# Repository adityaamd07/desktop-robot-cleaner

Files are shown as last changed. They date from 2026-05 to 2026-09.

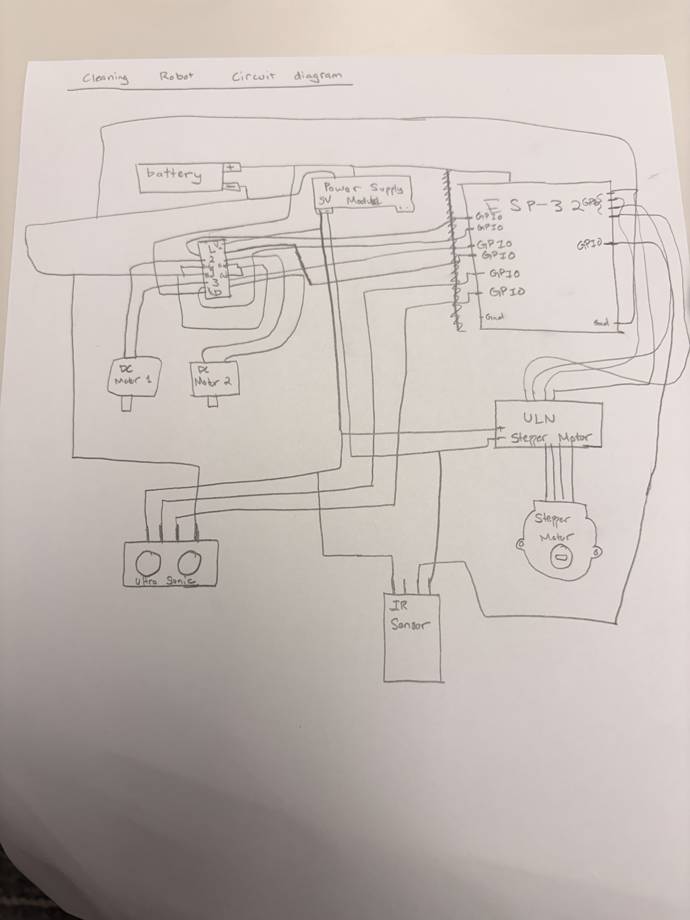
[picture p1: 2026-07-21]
docs/sketches/cleaning_robot_wiring_diagram_v1.jpeg

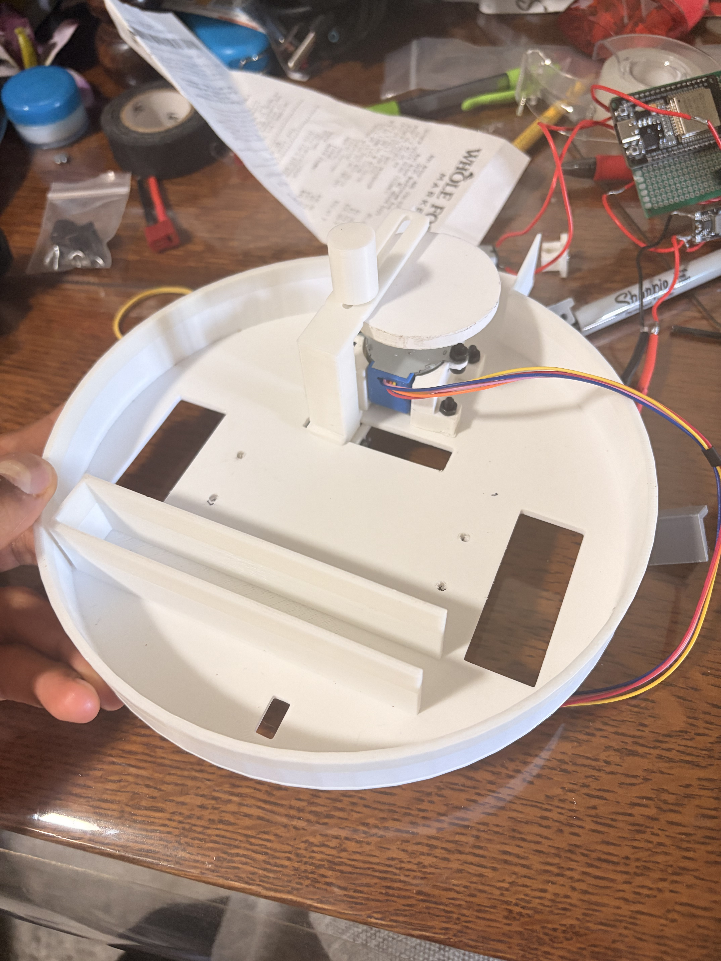
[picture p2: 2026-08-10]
docs/media/top_view_chassis_w_mechanism.jpeg

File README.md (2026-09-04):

# desktop-robot-cleaner
The goal of this project is for myself, a rising sophomore mechanical engineering student, to create a desktop cleaning with autonomous capabilities. The individual goals and markers of this project have changed quite a bit since its inception in May, but I have learned quite a bit by doing this and it has been a lot of fun!

**Project Status:** In progress

## Project accomplishments, current happenings, and future goals 
Since the project's start I have done the following: 
- Designed and fabricated a 7" circular chassis, ensuring that the chassis is able to fit tight space constraints between all components
- Designed a Scotch Yoke mechanism to move a cleaning pad back and forth, effectively sweeping areas. 
- Selected the proper materials, including chassis make, sensors, motors, and main chip driving performance
- Breadboard tested and permanently soldered components, utilizing IC sockets, screw terminals, and multmeter testing to ensure connectivity. 
- Designed a C++ firmware architecture using PlatformIO to have manual drive and sweeping capabilities

I am currently doing the following: 
- Attempting to synthesize C++ firmware, physical mechanisms, and electrical components together in one working system 
  by using the ESP32's bluetooth capabilities to handle manual driving and sweeping

Future Goals/Ideas: 
- Redesign chassis to be a 7"x 7" square, which will result in better use of space as many components are rectangular in nature
- Add autonomous capabilities
    - IMU + Encoders? 
    - Something else??
- Introduce a spray mechanism so the robot can sanitize a surface and sweep it in one pass. 

## Repo Structure: 
- docs
    - media: For all photos and vidoes I take during the project
    - sketches: a folder of all planning sketches I do for this project. To me, a planning sketch is one that I do simply to view an overall layout. Crucially, it does NOT have any dimensions. 
    - design_decisions: A log of decisions made throughout this project, including the rationale behind these decisions
    - materials purchased: a bill of all things bought for this project in order to keep tally of budget
    - components_list: a list of all components necessary for this project, both purchased and not yet acquired.
    - current: a planning document to organize tasks I need to accomplish in a given day, and the following days and week
- hardware: 
    - Chassis: all CAD models or engineering drawings including the full robot chassis
    - cleaning mechanism: all CAD models or engineering drawings/reasonings relating to the cleaning mechanism
- firmware: Used platformio in VSCODE
    - include: contains headerfiles
    - lib: any imported libraries
    - src: all source code
    - test: any test code
    - pio/build: ESP32 files preloaded by platformio
    - vscode: json files preloaded by vscode

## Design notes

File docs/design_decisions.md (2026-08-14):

# Design Decision Log

## Robot Chassis Shape -- 5/4/26
To begin this project, I considered two main shapes for the robot chassis: 

- Rectangular
- Circular 

I initially considered the rectangular shape because, to me, it simply made the most sense. 
Most of the electronic components are rectangular in shape, and it would be the most space 
efficient to have the robot be a rectangle, as then each component could slot in nicely. 
This has problems though: a rectangle is not as easy to maneuver as a circle, and for this robot to be autonomous,
it would have to be able to make fine tune adjustments in its position, which is much more difficult for a box to manage. 
Additionally, a rectangular shape would also likely require four wheels, would significantly increase the cost of the project, 
which is something I would like to avoid. The circular shape is less space efficient, 
but it is much superior in its maneuverability, which will make my life a lot easier when it comes to making this thing 
autonomous. According to my initial block sketches, the circle should contain enough space to properly manage components, 
and I can definitely find ways to make use of the shape to my advantage. 

**Decision:** Circular Chassis

## Chassis Diameter - 5/5/26
I considered a 6 in, 7 in, and 8 in diameter for the robot size. To determine the size that felt right for my desk, I drew a circle of 6, 7, and 8 in diameter on a sheet of paper and look at their relative size compared to my desk. I decided that 7 in would leave enough room for electrical components, while simultaneously allowing for enough manuverability for a desk my size. 
**Decision:** 7 inch diameter for chassis

## Robot Scrubbing Mechanism -- 5/5/26
I explored two options today of how to scrub the surface of its materials. The first option I considered is a rotating shaft that is in contact with the surface at all times. This design idea presented problems, however. Firstly, this rotating shaft would likely have to be a brush, not a dusting pad. A rotating dusting pad, to me, is not an effective way to clean, as the dirt is more likely to simply be spread out more rather than actually be collected. This, however, presented its own challenges. Even if I decided to do a brush, I would still likely need a dust  collection system so that the dirt is removed from the surface. This is much more mechanically complex, but also this is not very feasible to combine into a the second stage: santizing. How could I possible turn this dust collection system into a sanitizer? Suddennly, this begins to sound like two different machines.

The second option I considered is a oscillating dusting pad that is in constant contact with the surface. This option to me seems the better option. A scrubber that moves back and forth is much more intuitive, as that is how a normal person would dust a surface: scrubbing a swiffer back and forth. And, by using a swiffer pad specifically designed to collect dirt, I would rid the need of a dust collection system. This ties perfectly into the sanitizing stage: people sanitize surfaces by moving a clorax wipe or an equivalent back and forth, so it makes sense for a robot to do that as well. So, after dusting and removing larger debris, I can simply replace the dusting pad with a small mop pad, and my robot will instead turn into a sanitizer. 

**Decision:** An oscillating dusting that scrubs that surface back and forth

Further Questions for next steps: 
- How will I make the pad oscillate back and forth? The only way I know of to make things move in a robot is a motor. Is there any other way? Otherwise, how do I turn rotational motion into linear?
- How will I attach these pads to the robot?
- How will I change out these pads?

## Overall Drive train decision -- 5/11/26
I considered a few  options for my vehicle drivetrain, or how to actually get my robot moving. The first idea was to model my robot after a car: four wheels, two in the front and two in the back, each connected with a rotating shaft. I had considered using one motor to drive one of the wheel-shaft combo, but then quickly realized that I would have no way to turn the car. I then researched how a modern car handles steering: a rack and pinion setup connected to a steering wheel that would angle the wheels 

This was definitely interesting, but I deemed it far too mechanically complex for what I am trying to accomplish. Besides, this idea would require buying four wheels, which would increase cost. I then considered both a two and three wheel design. The two wheel design would be realtively simple: two wheels, one on each side of the chassis, each connected to a DC motor. These wheels would not be connected to a central shaft, but would fall in line along the diameter of the robot. This would allow for easy manuervering, as turning the robot would be as easy as turning one of the motors on and the other off. 

I also briefly considered a 3 wheel design. This would keep the two wheel system, but add a third castor wheel towards the front of the robot in order to achieve greater stability. For this design, I could either keep the two wheels at the diameter, or shift it further back, along a chord of the circle. For now, I will pocket this design. I plan to have the scrubbing mechanism in constant contact with the surface, so that _should_ provide enough stability for the robot to tip over. I will move forward with planning and building an initial prototype, and then after some testing, I will decide whether a castor wheel is necessary. 

**Decision:** two wheel drivetrain with each wheel connected to its own motor

**Further Questions:**
 - Given that I know what my wheels system looks like, can I begin writing code for driving the robot, assuming manual inputs?
 - I previously decided on an oscillating system to scrub. Where should I place this system? The front? The back?
 - Should I have two levels in my robot, or is one enough for the components I need?

## Chassis Layout Planning -- 5/14/26
I worked in MS Paint today to plan out my chassis, working through placing different components in my circular frame. I have arranged a preliminary layout, which can be found docs/sketches. The main thing I wanted to figure out was how to fit in the scrubbing mechanism, and the answer is that I have no answer. I need to decide on a scrubbing mechanism, and come up with sketches before I can go any further. I have some ideas on a way to lower the srubbing mechanism further down below the chassis floor, thus making leaving much more space on the chassis itself for other components. 

No decision made today. Any Further Question mainly revolves around how I am going to design this scrubbing mechanism. 

## Scrubbing Mechanism Sketching --5/21/26
I used a penci, a piece of paper, and a ruler to sketch out and define my mechanism. These sketches are visible in the hardware folder. I worked through many things. Firstly, I decided to use velcro command strips in order to attach the cleaning pads (duster or mop pad) to the mount. This allows for the simplest method of attaching and removing pads. An additional option I considered was using metal strips and magnets, but I was unsure whether the magnetic force would survive the scrubbing mechanism, and decided to go for velcro as the simpler option. I then, using the 7 inch diameter of my robot and the average length of a commmand strip as constraints, drew out my scrubbing mechanism. I decided on a 2.5 inch diameter wheel spinning, as this would allow for 5 inches of linear coverage, according to l = 2r, a governing equation for crank and slider mechanisms. 

Finally, I have decided to use a stepper motor to run the scrubbing mechanism. I initially considered a servo motor, but quickly realized that, for Phase 2 of this project, I will need to precisely move the cleaning pad mount to a certain spot to allow for consistent changing of pads. Thus, I decided to use a stepper motor as that will provide me greater precision that a servo. 

**Decisions**: Velcro linkages between pads and mount, 2.5 inch diameter wheel for crank and slider mechanism, and swapping servo motor with stepper motor

Further Questions:
- how will I link the pieces in my project together? screws? custom 3d printed joinings? 
- In my initial sketches, I assumed one velcro piece would be enough. Will this hold to be true? 

## Components Update -- 5/29/26
This is multiple design decisions rolled into one, so I will try an dedicate a few paragraphs, one for each decisions. First,  I decided on the G12 N20 DC motors to drive my robot. Upon research, I discovered that N20 motors are a classic choice for robots, so I decided to use them as a useful starting point for this project. I decided on the G12 N20 motors because this was the type that I found the most documentation for, which is useful when deciding power current requirements. 

I also decided to use the L293D motor driver and the ULN2003 Stepper Motor Driver for my DC and stepper motors respectively. The primary rationale for this decision is that they came with the ELEGOO kit that I ordered and are useful for prototyping. If needed, I will order a different motor driver. It is worth mentioning that, according to my calculations, the L293D driver does not provide enough current for my motors IF both of them stall. Ideally, I would design my system to avoid my motors stalling, but I will note this here and will likely replace the L293D as I move out of prototyping. Additionally, I have decided to use the power supply module given with the ELEGOO kit to regulate power for now. 

Finally, the battery. I first researched and noted the documented voltage and max current values for components that would need to connect to the battery. These values can be found in docs/commponents. By summing the max current values for the stepper motor, both DC motors, and the ESP 32 board, I arrive at 2080 mAh. Because I would like the robot to run for 30 minutes on one charge, I decided on a 1040 mA minimum current requirement. I then applied a 20% buffer (1040/0.8) to bring that number up to 1300 mAh. To be safe, I decided that 1500 mAh should be good for the battery. The DC motors require the largest voltage at 6V, and the VIN pin on the ESP32 is only able to handle up to 12V. To be safe, I decided to go for between the 5-8V range, which should be more than safe for the ESP32. Therefore, I decided to use a 7.4V Lipo Battery. This was one of the cheaper batteries I saw, yet simultaneouly met all of my requirements. 

These decisions ultimately provide a natural power architecture. The battery will connect to three components: The ESP32 VIN, which handles up to 12V, the L293D motor driver, and the power supply module. The power supply module will then power the stepper motor and its driver, both of which require 5V. 

**Decisions:** G12 N20 Motors for driving robot motion, L293D motor driver and the ULN2003 Stepper Motor Driver for DC and stepper motors respectively, power supply module from kit for voltage regulation. 7.4V Lipo Battery with 1500 mAh. Power Architecture has been decided. 

Further Questions:
 - What size wheels will I need for robot.
 - How many IR sensors do I truly need?
 - what is the true ESP32 current draw? My current number is a rough estimate. 

## IR Line Sensors Quantity and Placement + Robot Driving Pattern -- 5/29/26
In order to decide how many IR sensors I needed I first need to decide how my robot is going to move. I quickly decided on a lawnmower style pattern, with only forward motion and pivoting. This is the simplest way I could think of to code the robots motion, and will make planning this project much easier. Therefore, I have decided on 2 IR sensors, one in the very front and one in the very back. When the Robot is moving forward, we will obviously need a sensor in the front to detect when the robot is off the edge. When pivoting, however, the front and back of the robot will travel in a arc around the wheel that has been designated the pivot. Obviously, whatever wheel is pivot will depend on the direction turning, but this means that the front or back will likely move off the desk if close to the edge of the desk. Having these two sensors here will prevent that from happening. 

**Decision:** Lawn Mower Traversal pattern and 2 IR sensors in the front and back for edge detection. 

## Wheel Diameter size  -- 5/31
After sketching a quick dimensioned paper sketch (visible in docs/sketches folder), I have decided on 3 inch wheels for the drive train of this robot. This decision was made primarly due to an estimated thickness of a swiffer dusting pad. Unfortunately, I do not have access to the actual swiffer pads for the moment, but online estimates ranged from 1.5-2" when fully fluffed. To get the effectiveness of the pad, it will need to be compressed. Thus, I decided to allocate roughly 1" of space below the robot for the pad itself, with 0.5" for the mount to hold the pad.

With 1.5" of space below the robot, I naturally concluded that I needed 3" diameter wheels. I had already planned on keeping the motor housing for the wheels inside the chassis, which would mean that the middle of the wheel would have to be in the chassis, in line with the motor axle. This mean I would need a 1.5" radius wheel to keep the robot 1.5" off the robot. Additionally, I have only ordered 2 wheels for now. I will test using the scrubbing mechanism itself as a third point of support: if this is too unrealiable, I will research and decide to implement a caster wheel.

**Decision:** 3" wheels will be used in drive train system. Will consider caster wheel after first prototype. 

Further Questions: N/A

## Wheel Diameter resize + Dust Pad change  -- 6/23
I've been on vacation for a while, so work on this project has slowed, and I have gotten lax at updating this repo. I've been working on the robot chassis design in my free time, and have since recognized that I simply cannot fit everything in as it stands with 3 inch wheels. With the battery I have chosen and the restraint of a 7 inch diameter, there simply isn't enough space to fit everything in as it stands. Thus, I've decided on downsizing to 2 inch wheels, which will give me roughly 1 inch of ground clearance. I feel comfortable with this due to a recent discovery I have made: swiffer dusting pads. Previously, I was working under the assumption that I would be using large, handheld fluffy dusting pads for my robot. I have since visited target and discovered that swiffer actually makes thinner, dusting pads intended to be put on a mop. With these, I can assume the pad has negligable thickness and not be concerned with fitting a thick pad under my robot. 

**Decision:** 2 inch wheels will be used in the drive train system, and I will be switching to thinner swiffer dusting pads. 

Further Questions:
 - How will I acquire these new wheels? 3D print or buy new ones?
 - How will I keep track of the distance that the robot moves? Math or a device?
 - For this robot to work, I will need both the ultrasonic sensor and the IR line tracker in the front of the robot. How will I reconcile the fact that both these devices need to take up a similar about of space?

 ## Wheel acquisition -- 6/25
 After some thinking, I have decided to buy wheels online. This is a bit unfortunate because I already bought some 3 inch wheels that are now useless, but I digress. After researching online, I have discovered that the tolerances to make these wheels fit into the the motor are very finnicy for a 3D printer, and that the DC motor I have chosen, G12-N20, already has wheels that you can buy for cheap on amazon. Thus, I am deciding to buy one of these wheels, which I will order soon. Now this does come with a drawback, which is that the only wheels that I can find are 43 mm wheels, which is roughly 1.7 inches. This is slightly smaller than the wheels that I originally wanted, the 2 inch wheels. This will leave me even less ground clearance than I originally intended. I have decided that to work with this, and attempted to make my cleaning mechanism fit in the roughly 0.85 inches of ground clearance I know have. 

 **Decision:** I will purchase my wheels for the drive train. This will shrink my ground clearance, which I have decided to work with. 

 Further Questions:
 - How should I opt to fit in my cleaning mechanism under the robot now that my space has shrunk. 
 - How will I make the cleaning pads replacable? 
 - How should I think about mounting my step motor to the chassis to drive the cleaning mechanism. 

 ## Cleaning Pad -- 7/4
 Because I have now switched to the thinner dusting pads used on maps, I now have a greater degree of flexibility in deciding the length of the cleaning pad itself. I have decided on a 4x2 inch cleaning pad dimensions, which I will note in my components list. I arrived at this number largely as a reasonable guess to what would a good length be. 8 inches of surface area to clean should certainly be a big enough number for a countertop/desk while still being small for the robot, and this will also make it (roughly) the size of my velcro strips. This makes it so that there is little overhang from my cleaning pad over my velcro strip, which I believe is preferable. This dimension is very much subject to change as I begin to run the numbers and decide if the mechanism I want to fit is possible. 

 **Decision:** Cleaning pad length will (temporarily) be 4x2 in. 
 **Next Steps:** Based on this length, redo all of the math and redesign the cleaning mechanism with the chassis and this new constraint in mind. 

 ## Cleaning Mechanism significant redesign -- 7/4
 I have had a significant realization while working on measuring out this cleaning mechanism. I kept running into the issue where I was struggling to balance the amount of space I had. with the constraint of the 6.5" chord, I simply could not figure out a way to balance the lengths. This was especially hard due to my realization that, since I am elevating the motor shaft above the floor of the chassis, the length of the slider is NOT simply 2 times the radius, but a little more than that, which would involve a lot of decently complex math to do so, as it introduces an angle of elevation since the crank arm is not perfectly inline with the slider. By using a linkeage system and having the crank and the slider side by side, I simply would have to make the slider so small that the cleaning pad would be hardly oscillating, which to me, defeats the whole purpose of having an oscillating cleaning pad in the first place. 

 This resulted in me researching other ways for me to convert rotational motion into linear motion. I have since arrived at the scotch yoke mechanism. With this mechanism, the crank arm is able to sit perpindicular to the slider, which means that I can place my stepper motor above or below the slit in the floor, where I have signficantly more space than I do right now. This will greatly simplify my design. Best of all, the mechanism uses a simple L = 2r for the slider length, and does not require the complex math that the linkeage system does. 

 **Decision:** Shift from a linkeage system to a scotch yoke system for my cleaning mechanism. 
 **Further Questions/Steps:** From here, I need to start sketch what this system will look like and dimension it on paper. From there, I can CAD the model and have it ready to be added to the main chassis assembly. 

 ## Step Motor Mount -- 7/6
 I have just finished designing my Step Motor Mount, which can be found for the time being in hardware/chassis. For the future, I might add a mounts folder in hardware due to the fact that I have design multiple mounts throughout the project. Design for this mount was pretty straight forward, although the main decision here comes at the walls of the mount. The way I have it, the walls are very thin towards side holes for the motor. I worry about structural integrity of the mount with such thin walls, but I have for the time being decided to keep this as the first version and design a different mount later. 

 **Decision:** Use current iteration with thin walls for the Step Motor Mount, and decide in the future whether the mount needs redesigning. 

 ## Cleaning Mechanism decisions -- 7/6
 Two decisions to report here after doing CAD on the new cleaning mechanism. The first is relating to the "crank arm" of the mechanism. I have decided to use a circle attached to the motor shaft for this project, because I deemed it simpler to design while getting full functionality. I worried particularly about accidentally designing an arm too small and thing that would snap, and with a circle, the chances of that happening dwindle significantly. On a practical note, using a circle made it easier to see the amount of space the mechanism would be taking place, rather than a single arm where I would have to visualize its path through one shaft rotation. Additionally, I have decided on a crank radius of 1 inch, for roughly 2 inches of travel. 

 The second relates to the crank pin. I initially considered designing and 3D printing a dowel that would fit into the circle, and thus be used to shift the cleaning pad as the wheel turned. I worry, however, that the plastic on plastic friction will degrade the dowel, and make the mechanism fail over time. I have thus decided to use a a steel rod as a dowel, that I will cut to length. Plastic on metal should result in a much smoother glide, and importantly, should not seriously degrade the plastic over time. 

 **Decisions:** 2 inch Circle with steel rod pin for the crank arm. 

 **Further Question:** What size steel rod should I use for the pin, and will choosing to do this increase my costs severely? 

## Cleaning Mechanism Decisions  -- 7/7 
Today, I have finished my second version of the cleaning mechanism, which is very exciting. One of the decisions I arrived at today was deciding the size of the steel dowel I will use. For simplicity, I will 3mm dowel, as I found multiple 3mm steel rods for relatively cheap on Amazon. 

Additionally, I must begin to consider the actual attachment of the cleaning pad. For this, I was considering designing a piece that will hold a velcro strip that the cleaning pad will attach to, and then towards the top of that piece, a place to put an adhesive magnet. The main reason I want to use magnets to attach the final piece holding cleaning pad is ease of transfer. By using a magnet, replacing the cleaning pad becomes as easy as peeling off the final piece, rather than unscrewing a part of flipping the whole robot over. Even better, I know observationally that it is decently difficult to slide two magnets off of each other, but relatively easy to peel them off. This means that the piece should not slide off during the lateral motion of cleaning. 

**Decision:** 3mm steel dowel for crank pin, and using magnets to attach the piece holding the cleaning pad for the cleaning mechanism. 

**Further Steps:** Begin deciding on electrical component placement, design the last mounts, and research the materials necessary for a sanitizing pump. 

## Project Scope Redefining -- 7/7
As I continue to work through this project, I begin to realize that the scope of this project is vast, far vaster than I originally intended. And while I think much of the complexity of this robot is good, I do believe that a certain aspect of the project is needlessly complicated: the stage two pad swap. 

Originally, I determined the need for a two phase system based on the fear of smearing. Basically, that if I straight away sprayed a sanitizing solution and scrubbed back and forth, the debris and dirt would simply smear on the surface rather than be properly collected. I have since decided that this is no longer a worry. A desktop is many scales smaller than a floor: I'm betting that the volume of debris is proportionally scaled down as well, enough to where smearing is a nominal issue.

This also helps my project timeline, as it reduces the number of subsystems I need to design, and focuses in on the core of the project: an autonomous desktop vehicle that fully traverses a desktop/countertop. I am therefore redifining the project as follows:

The project is a desktop sweeper and sanitizer, that travels the area of the desk and simultaneously sweeps and sanitizes it using a scrubbing cleaning pad and sanitizing spray. Phase one of the project involves creating the robot with the cleaning mechanism and spray, and being able to control the robot through bluetooth commands. Phase 2 of the robots will involve making the robot fully clean any square or rectangular surface autonomously. I hope for this redefinition to realign my goals and better narrow the scope of this project. 

**Decision:** Eliminate the prior phase 2 pad swapping, and focus purely on making an autonomous robot that sweeps and sanitizes the surface in one pass. 

**Further Questions:** Is my bet right, or will smearing occur with only one pass through?

## Sanitizer Decisions -- 7/9

**DECISION ONE: SETUP TYPE**

Now that I have finished my first design of the cleaning mechanism and am ready for testing the physical model of it, I have turned my attention to the santizing system. I first researched the different types of pumps used and found two main setups for hobby projects like mine: a submersible DC pump, or a external peristaltic pump. I have chosen to use the submerisble DC pump, for a few reasons. Because this is my first project that I am attempting, I am foing my best when possible to choose the simpler option, and the DC pump, according to my own research, is the simpler choice to implement. Additionally, I found that it is cheaper to set up and more space efficient, since it combines the pump and liquid resevoir together. 

**Decision:** Submersible DC pump will be used to drive sanitizing mechanism

**DECISION TWO: RESEVOIR SIZE AND TYPE**

Now that I have decided the pump set up, I now bring my attention to the resevoir. From my own research, I estimated that the average spray nozzle releases roughly 1 ml of liquid per squirt on the medium range. From my 5/29 decision, I have decided on a lawn mower style traversal pattern, and I am envisioning no more than 2 squrts per forward traversal of my robot. If we imagine that the typical desk requires at most 5 forward traversals from start to finish, then we are looking at a maximum of 20 spurts, or 20 ml of liquid. I would like one refill to allow for 5 cleans, so we are looking at a rough estimate of 100 ml of liquid. This will serve as my starting point for the project, and I will change this number if needed. Additionally, because I would like the resevoir to be easily refillable and conform to the limited space I have in my chassis, I have decided to design my own resevoir. 

This comes with issues: won't the presence of liquid risk mold growth in my 3D print, especially if I am using PLA? For the time being, I have decided to mitigate this by committing to a very strong chemical cleaning spray that is naturally anti microbial growth to mitigate this. I will redesign if it soon becomes clear that the resevoir is building up mold. 

**Decision:** A custom designed, 3D printed resevoir with 100ml capacity will be used, with 100ml subject to change later

**DECISION THREE: NOZZLE TYPE**

Finally, I have elected to go with a fan nozzle for maximum coverage. I want the entirety of the cleaning pad to have some of the liquid on it to make sure no gaps are made in cleaning, so I would like to cover most of the 6.5 in chord (maybe 4-5 in of it, give or take), and a fan nozzle will grant me that coverage. To decide on the angle, I will order a few different angles and pick the one I like the most

**Decision:** Fan nozzle to be used for maximum coverage of surface area. Ordering multiple (2-3) angles to decide on the best one. 

**Further Questions:** 
 - How will the introduction of the resevoir change my weight distribution?
 - How shall I plan my space so everything manages to fit into my chassis?
 - Which nozzle size will end up being the right size for me?
 
 ## Components Wiring Diagram -- 7/22
 I have drawn an initial components wiring diagram, which can be found in /docs/sketches. Keeping with my 5/29 decision, I am keeping three things plugged into the battery's positive terminal. The diagram includes components such as the Ultrasonic sensor, L293D, two DC motors, and the stepper motor driver and stepper motor, and the IR sensor. I haven't yet figured out the exact setup of the sanitizer, so I will leave that up in the air. 

 This is a really straightforward design decision, but I think the steps that come with this are more interesting. I will be using wokwi to plan out with GPIO pins of the ESP32, and start trying the preliminary code to try and see if it will work. Additionally, I will be getting a Caliper tomorrow, which I will use to finish blocking out the 3D model to make sure I have enough space in the current model to fit all my components. 

 No further questions. 

 ## Switch from Power Supply Module -- 7/24
 I have decided to switch away from the power supply module for my project, and instead switch to a cheap voltage regulator that drops the voltage down to 5V. I have done this for two reasons. The first is that the power supply module is made for breadboards, and I want this project to be on PCB, for permanentability and to learn soldering, so soldering this power supply to a PCB is very difficult. The second reason is that the power supply module is very large, coming in at over 2 inches long. This is a lot of space, which is a very limited resource for me since I have decided to (mostly, I expanded some parts of the chassis) stick to the 7 inch diameter chassis. Thus, it simply makes sense for me to switch to a voltage regulator, which is much smaller, as both its length and width are under one inch. 

 **Decision:** Switch from power supply module to voltage regulator

 **Further Questions:**
  - Where should I place the voltage regulator to optimize space?
  - Where should I place ALL components to make efficient use of my space?

  ## Reprinting parts - 7/30
  I have printed the first parts for the robot. I have decided to reprint the sliding arm for the cleaning mechanism, as it was extremely delicate after the first print and snapped. I have doubled the thickness, so hopefully this will last better. Additionally, after some intial testing, I realized there wasn't enough holding the sliding arm into place to truly translate into linear motion. I have redesign the conecting piece to include some support from the bottom of the chassis to ensure that the sliding arm is only moving linearly, and not shifting diagonally 

  **Decision:** Reprinting components of cleaning mechanism to improve functionality of said mechanism 

  ## PCB and component mounting 8/4
  I have started truly soldering, which has been great. One thing I did not anticipate is have a bunch of wires below my PCB for wiring components to my ESP32. Thus, I have decided to design some mounts that would elevate my PCB above the chassis floor, which will allow some space for the wires to flow. This doubles as a space saving mechanism, as this clears up some space on the chassis floor (now below my PCB) for my motors, which previously did not have the space to place. I will spend the rest of this week trying to wire and get as many components on the chassis as possible, and will begin thinking about the sanitizing and code next week. 
  **Decision:** Designing mounts for the PCB to elevate above the chassis floor, and designing mounts for other electrical components, such as the stepper motor driver and the voltage regulator

## Restarting wiring process - 8/8
Today, after having soldered my motors and ESP32 to a PCB, I tried to connect my ESP32 to my laptop and failed. This resulted in one, horrifying conclusion: I somehow managed to ruin the usb connection point on my ESP32, thus resulting in windows devices not recognizing the chip. This cannot be proven, but after 3 hours of constant debugging and testing, it is the only conclusion that I can come to, as no solution worked for this. I have thus come to the only solution that I can: restarting. I have ordered a new ESP32 chip, and will spend next week soldering components together to try and complete this project. This is obviously a huge set back in my project, both time and cost-wise. 

This has been a big blow to my morale, but I am going to try my hardest to not let this affect me. While I am waiting for my new board, I have decided to begin development on my firmware. I am planning on using the ESP32 to create a web server where I can send commands from my laptop to the board. This way, I can autonomously command the robot to begin cleaning in the future. I will begin development on both this and basic movement options while I wait for the new components to arrive. 

Because of this set back, I am also quickly running out of time before school starts. Therefore, I have decided to focus on solely a drivable robot that can sweep items. For the time, I will make the sanitizing part of this robot a phase 2 problem, and make phase involve a drivable, sweeping robot. If I move faster than I expect on my schedule, I will adjust accordingly. 

Finally, although this was kind of a downer of a design decision, this does give me the chance to greatly improve upon on how I think about soldering and PCB. For starters, in order to avoid messing up my boards like I did this time, I will be using IC sockets on my PCB, rather than soldering components directly to my PCB. This should avoid connection issues like what happened with this time. Secondly, in my previous design, I left all wire connections beneath the board. This was a grave mistake. It led to a jumbled mess of wires below the board, and made it impossible to even conceive mounting my PCB to the chassis. I will be leaving all my wiring above the board this time. 

**Decision:** Redoing all soldering due to non responsive ESP32. Will iterate, using IC sockets to avoid direct soldering of components, and a more structured approach to wiring, making PCB mounting easy. Will begin to early work on firmware code to speed up process, and moved sanitizing spray to phase 2 to ensure phase 1 completion before summer's end.

**Further Questions:** 
 - What pins am I going to assign to what components?
 - Even though it is phase 2, it is worth planning out how I am going to make this robot autonomous now for easy transitions
 - will I need to reprint the chassis to fit in necessary components?
 - The ultrasonic sensor sends out 5V signals through its echo pin. Will I need to use resistors to step this down for the ESP32's 3.3V pins? How will this work?

 ## Header File Organization + RME Convention -- 8/9

 I began writing .hpp files for controlling my motors and sensors. For these header files, I have decided to document using definied Abstract Functions, Representation Invariants, and definied RMEs **when necessary.** Crucially, I did not want to spend a ridiculous amount of time documenting when that time could be spent coding, so I have decided to always specify an AF and Rep Invariant, whether or not they exist. For general methods, I will either use a comment line describing the method or an RME, depending on what the methods functionality is. I suspect that RME's will not be required until I begin designing my autonomous navigation. 

 **Decision:** Adopt AF and Rep invaraint documentation (or lack therof) in my code, and RME when I feel appropriate

 ## Motor and Sensor Data Representation -- 8/9 
 
 When I was designing on my header files, I came up with two distinct data representations for each case. For the motors, I decided to use an enum class to represent the driving state of the robot, and set up a rep invariant that the current state of the robot must match one of the listed driving states in the enum class. This has a few advantages: there truly are only a select number of states that the robot can drive in, so this helps eliminate undefined robot behavior. Addtionally, this lets me set specific requirements for each state, or perhaphs in between states (like not turning too fast after driving straight or backwards). 

 For the Sensors, I was more conflicted. I considered using a state representation like I did for the motor, where I would continuously store and update the state of each sensor. This would be helpful for autonomous driving, but is a little more complicated to design currently. Therefore, I have decided to simply create a set of boolean functions that translates the sensor data into actioanable items (does floor exist? or is object in front too close?). This simplifies matters for now, which is why I have tentatively decided on this structure. However, this may need to change in the future as I design autonomous travel. 

 **Decision:** State based representation for motor control, and (tentatively) statless representation for sensors, where information is not stored in a vairable, only updated through boolean methods

 **Further Questions:**
  - Should front and back floor sensors have multiple public methods, or just one public method?
  - is there ever a scenario where the front and back IR sensors will both read that the floor does 
    not exist?

## Pinout Assignment -- 8/10
I have decided on and assigned pins of the ESP32 to be wired to the various motor drivers and sensors. The list is as follows: 
 - L293D
    - 25, 26 --> Left Motor Input pins
    - 32 --> Left Motor Speed Control
    - 27, 14 --> Right Motor Input pins
    - 33 --> Right Motor Speed Control
  - Ultrasonic Sensor
    - 18 --> Trig Pin
    - 19 --> Echo Pin
  - IR Sensor
    - 16 --> front IR sensor digital pin
    - 17 --> back IR sensor digital pin
  - Stepper Motor 
    - 4, 13, 21, 23, --> IN1, 2, 3, and 4 respectively. 

These pins were chosen in accordance with an ESP32 pinout I saw, and I tried to choose the safest pins I saw for the task at hand. 

**Decision:** ESP32 pins assigned as above

**Further Questions:**
  - Will I have enough ESP32 pins to wire another L293D for the submersible motor for the spraying mechanism in Phase 2

## ESP32 mount adjustment -- 8/11/2026

With my new order of an ESP32, I also acquired a socket board with screw on terminals for the ESP32. While I am happy with this decision, it did come at one glaring cost. The size of the socket board is much larger than anticipated, so I will need to compensate. I originally had printed some mounts to elevate my ESP32, but now that height is no longer enough, as the ESP32 in the socket board would slope due to the battery interfering. Therefore, I have decided on the simplest fix of elevating my ESP32 more, higher than battery so it can sit flat on these new mounts. I will, therefore have to redesign the mounts in question to make them even higher, but this should resolve this issue. 

**Decision:** Elevate new socket board with screw terminals higher than before, above the battery on the chassis so that it sits flat. 

## Stepper Motor Firmware Architecture -- 8/14/26

Today I moved off the Arduino Stepper library entirely for driving the cleaning mechanism's set up. The library's step() call is blocking and doesn't return until the full commanded rotation finishes, which interrupts all other ESP32 functions. This would ruin my Phase one goal of a WIFI controlled robot, so I replaced it with a hand-rolled half-step driver. I used an 8-row lookup table of pin states, and a function that advances through the table and writes the four IN pins directly. This gives full control over timing, allowing components to operate essentially simultaneously. 

I also restructured the cleaning mechanism using three states: SWEEPING, RESETTING, STOPPED. Each state is triggered by an explicit public method (start_sweep(), reset(), stop()), and the per-loop sweep function reacts to whatever state is currently active. This ensures nothing is blocked from running, while cleanly interacting with my idea for an implementation of the web server.

While building this, I confirmed by hand-spinning the mechanism that a full 0-360 degree rotation of the stepper motor is not possible: something in the way I printed and assembled the mechanism only allows for 0-180 degree rotation. Rather than spend my time figuring out what the physical blockage is that is preventing the alst 180 degrees of rotation, I shifted my software to have my stepper act as a servo: oscillating between 0 and 180 degres, which still allows for the full stroke length to be travelled by the mechanism. As a safety margin against the jam I confirmed by hand, I capped the sweep range at 172° rather than the full 180°, applied evenly through the stroke. 

I breifly considered adding an encoder to my stepper motor to hard code in a initial starting position each time the robot resets. I have decided to pause this for now. For getting my initial prototype built, I have deemed an encoder unnecessary, so I will defer that decision to a later date, after this first prototype has been up and running. 

**Decision:** Hand-rolled non-blocking half-step driver replacing the Stepper library; three-state (SWEEPING/RESETTING/STOPPED) architecture with explicit trigger methods; bounded 0°–172° oscillation confirmed safe by hand-testing; hardware homing deferred to Phase 2/3 chassis rebuild.

Further Questions:

How will the stepper's non-blocking pattern extend to the DC drive motors and future sensor polling — same millis()-gated approach per subsystem?
Once the webserver is running, does the actual physical sweep timing (interval = 2ms/step) feel right, or does it need tuning after seeing it move on the breadboard?
When I do add a tactile-button endstop later, does it change anything about the current current_position/RESETTING logic, or does it just add a new state/trigger on top?

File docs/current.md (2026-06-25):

# Current 

This is a planning doc that I am creating to better understand the amount of time that I have to undertake this project. I plan on updating this every so often to detail what I have accomplished in the past few days, and what I plan to accomplosh in the next few days. I hope to hold myself to a good schedule by doing this. 

## 5/14
Today, I messed around with the ultrasonic sensor and the DC Motor. I learned much about how to wire these two together, as well as more about the power supply module and connecting external power sources and handling multiple power sources and grounding. I also did a preliminary sketch of the chassis. Tomorrow, and in the coming days, I hope to fully draw and CAD a design for the scrubbing mechanism. I also want to finish the mini project with the ultrasonic sensor that I am doing. Towards the end of this week and the beginning of next week, I want to have most of my components bought and ready, and be working through a full chassis design. 

## 5/21 
I was truly overwhelmed and was not able to work on this project the last week, which is frustrating. Today, I made great progress in sketching out the cleaning mechanism. Tomorrow and the day after, I hope to fully CAD this design, and hopefully send it to the library 3D printer on Sunday. In the following week, I hope to draw out and CAD the robot chassis, as well as figure out all components I need and get them ordered. My current goal is to have everything I need to assemble phase one of this project by next Sunday. Hopefully I can make this happen.

## 5/26
My original plan got delayed, but I think thats just something that I should begin to expect. Today, I finished my CAD model of the cleaning mechanism prototype. Tomorrow, I want to finalize and order all of the remaining parts that I will need for the Project. This includes sensors, wheels, motors, and anything else that I cant think of. I will be unable to work on anything with electronics or 3D printing after Jun 6th and up until July 12th due to vacation. I hope to be able to finish Phase 1 before I leave, which will let me design phase two parts over my vacation. 

## 5/29
At my current rate, I will likely not be able to finish Phase 1 before my vacation, which I have made peace with. Today, I finalized all my components except my wheels and the distance detection attatchment that I was thinking about. I also decided on the number and the amount of IR sensors. I made quite a bit of progress today. Moving forward, I want to finalize my cleaning mechanism CAD, and schedule an appointment with the library to have it printed. I also want to figure out the size wheels that I need, and begin designing my robot chassis. 

## 6/1
I have finished my version 2 of the cleaning mechanism. I added in the screws to allow for pieces to connect together, and I have put it in an assembley this time, which is awesome. Unfortunately, it is not looking like I am going to be able to 3D print a prototype before I leave for vacation, as the library has not gotten back to me yet for an appointment. Regardless, I am proud of what I have accomplished so far. Moving forward, I will be focusing primarily on robot design. I will be working on the robot chassis design over the break, and will start planning for the electronics diagram and thinking about the pad changing mechanism. Additionally, both the Ann Arbor Library and the Umich Library only accept STL files for 3D printing, so I will stick to STL files in my repo moving forward. 

## 6/25
I am not going to lie, current as an idea is not a great idea, as I almost never update it. That's fine. I have been chugging along on making my robot chassis. I think the bare chassis is almost done, and I just have to focus on making mounts now. I need to design mounts for the G12 motors, which should be easy, and the step motor, which will be significantly harder. After that, I'm going to start researching solutions for spraying a cleaning liquid on the ground. I think that I am making good progress, but I am going to have to crunch once I am back in Michigan (which will happen July 15th). I will have a lot to 3D print and a lot to solder, but it is looking to be very fun.

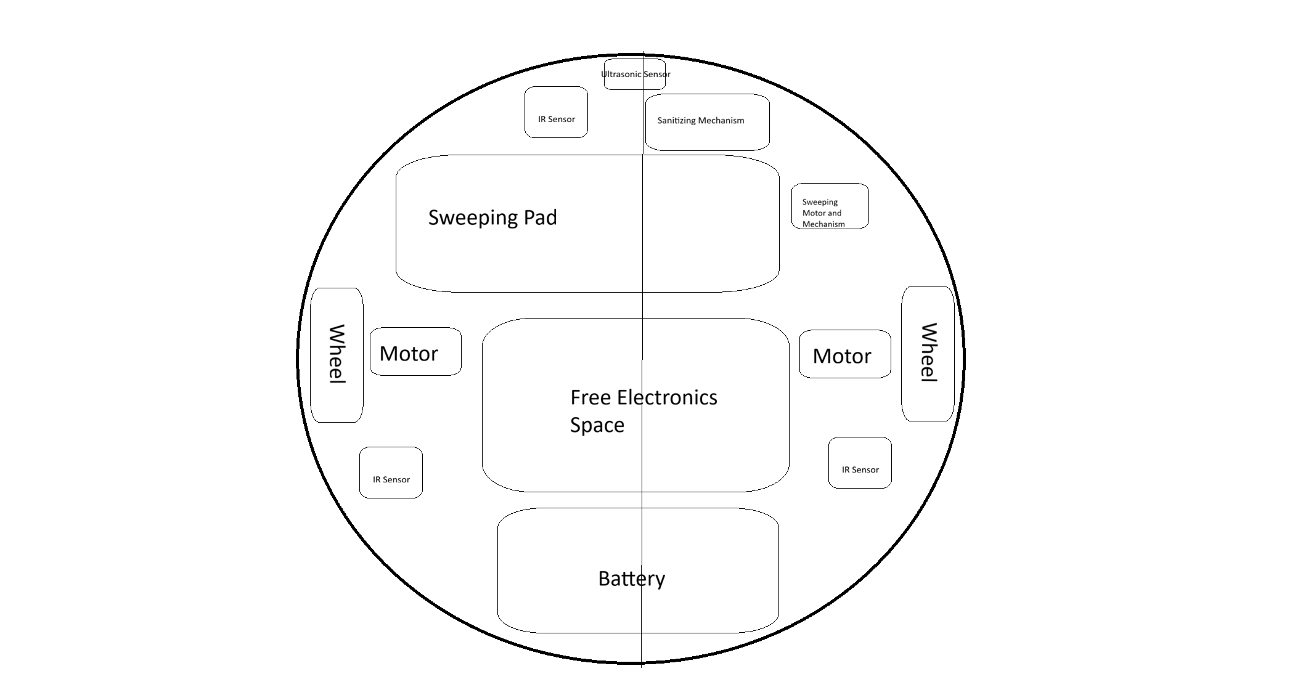
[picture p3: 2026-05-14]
docs/sketches/chassis-layout-v1-2026-05-14.png

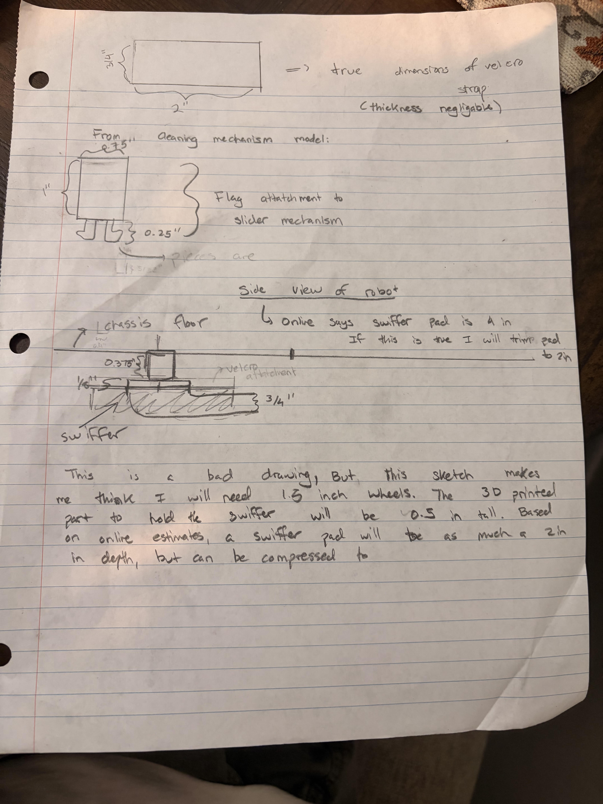
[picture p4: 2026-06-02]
docs/sketches/chassis-wheel-diagram-sketch-2026-05-31.jpg

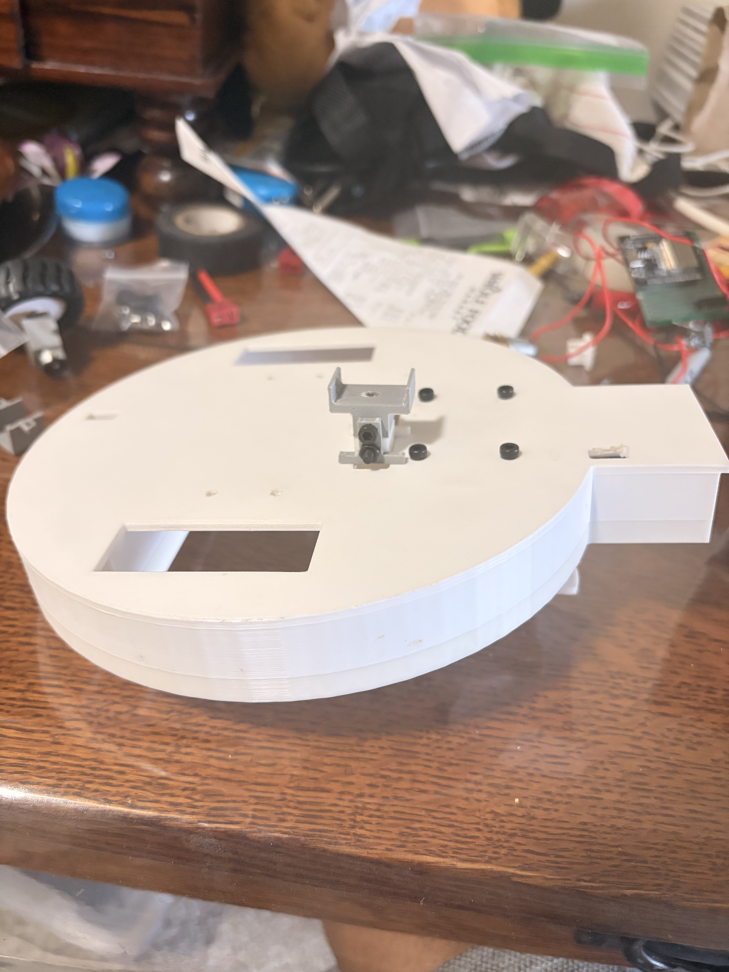
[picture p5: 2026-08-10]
docs/media/bottom_view_chassis_w_mechanism.jpeg

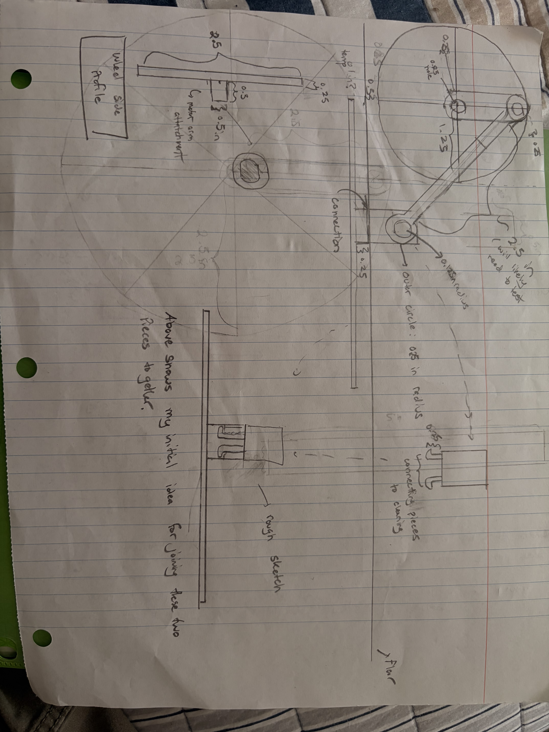
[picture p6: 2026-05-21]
hardware/cleaning_mechanism/cleaning-mechanism-2D-img2-2026-05-21.jpeg

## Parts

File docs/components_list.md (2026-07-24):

| Component name | Purpose | Quantity needed | Operating Voltage | Max Current Draw |  Dimensions |  Comment | 
| --- | --- | :---: | :-----: | :--: | -- |  :--- |
| ESP32 DevBoard | Microcontroller | 1 | 5-7 | 500 mA (conservative estimate) | 53.1 x 28.4 x 4.5 mm | Component included in ELEGOO starter kit | 
| Ultrasonic sensor | Detect objects directly in front of robot | 1 | N/A | N/A | 20 x 45.3 x 14.7 mm | Component included in ELEGOO starter kit. Will likely place one sensor in front of robot, with no need for more ( may change) | 
| IR Line Sensor | Detect surface (and lack thereof) underneath robot | 2 | N/A | N/A | 31 x 14 x 7 mm | ordered a pack of 5 as that was lowest amount I could find |  
| Step Motor 28BJY-48 | Source of Motion for Scubbing Mechanism | 1 | 5V | 240mA (highest estimate) | -- | Component included in ELEGOO starter kit | 
| ULN2003 Stepper Motor Driver Module | Driver board for Step Motor | 1 | 5V | negligable | 31.2 x 35.0 x 9.8 mm |Component included in ELEGOO starter kit
| G12-N20 DC Driver Motors | Turn Wheels | 2 (ordered 3) | 6 | 0.67 A each | 9.9 x 25 x 11.9 mm | I have not thought about sanitizing pump so far, but I could potentially drive it with this extra motor |
| L293D Motor Driver | DC Motor Driver Board | 1 (so far) | Maximum Voltage of 36V | 1.2 peak output | 19.0 x 7.9 x 5.0 mm|This component wil likely need replacing as it may not be able to provide enough current if a motor stalls. That said, it came with the ELEGOO kit so I am fine to using for prototyping for now. Additionally, I will likley need an additional motor driver to drive the sanitizing pump | 
| OVONIC Lipo Battery 7.4v 1500mAh | Power for ESP32, Motor Drivers, and Power Supply Module | 1 | N/A | N/A | 125 x 21.5 x 12.5  mm | N/A | 
| Voltage Regulator | Regulate Volage to all components in my build | 1 | N/A | N/A | 17 x 11 x 3.6 mm | Using this Voltage regulator specifically for its ability to be soldered and its smaller size | 
| round magnet | attaching mechanism for cleaning mechanism | 2 | N/A | N/A | 8 x 1 mm | N/A
| M3 Bolts and Nuts | Attaching mechanism for build | ? | N/a | N/a | M3 | Got a big kit of a lot of these
| stainless steel rod | Part of cleaning mechanism, built for cleaning mechanism | 1 | N/A | N/A | 3mm diameter, length as needed | Ordered long rods and will cut to size | 
| N20 Gear Motor Wheels | Drive train wheels for the project | 2 | N/A | N/A | 43 x 19 x 3 mm | Bought these as a replacement for my other wheels that I bought: it is a shame that I bought those wheels and I regret it |

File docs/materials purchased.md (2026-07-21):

| Item Name | Unit Cost | Quantity | Total Cost | Comments |
| --- | :---: | :---: | :---: | :--- |
| ELEGOO ESP32 Super starter kit | 35.99| 1 | 35.99 | Bought this kit in order to teach myself the basics of electronics. This kit contains many components I will need in the final project, such as the servo motor, esp-32 board, and ultrasonic sensor, so it should be a cost save to just buy this kit |
| 3 Pack G12-DC Motors | 3.99 | 3 | 11.99 | N/A |
| 7.4V Lipo Battery | 14.49 | 1 | 14.49 | N/A | 
| 5 Pack TCRT5000 IR sensors  | 1.099 | 5 | 5.99 | N/A | 
| M3 screws and nuts kit | 5.38 | 1 | 5.38 | N/A | 
| Copper Wire | 7.88 | 1 | 7.88 | N/A | 
| PCB board | 7.99 | 1 | 7.99 | N/A | 
| 5 PCS steel rod | 4.99 | 1 | 4.99 | N/A | 
| 4 pack N20 wheels | 7.97 | 1 | 7.97 | N/A | 
| Round Magnets | 7.99 | 1 | 7.99 | N/A |
| 7.4V LIPO Battery USB Charger Cable | 6.99 | 1 | 6.99 | Bought as a charger for my battery | 
| Wire Stripper | 4.49 | 1 | 4.49 | Realized that I didn't have a wire stripper, which is not good for when I need to solder wires together | 
| T Plug Connector Female and Male Deans with Silicon wire ends | 1.099 | 10 | 10.99 | This is an adaptor for my battery, but unfortunately it only had a 10 pack on amazon that I could buy | 
| Digital Multmeter | 8.99 | 1 | 8.99 | I don't have a Multmeter, and this could be useful for debugging circuits | 
| Digital Caliper | 5.99 | 1 | 5.99 | I've been struggling to find dimensions online, so I decided to buy a caliper to make my life easier |

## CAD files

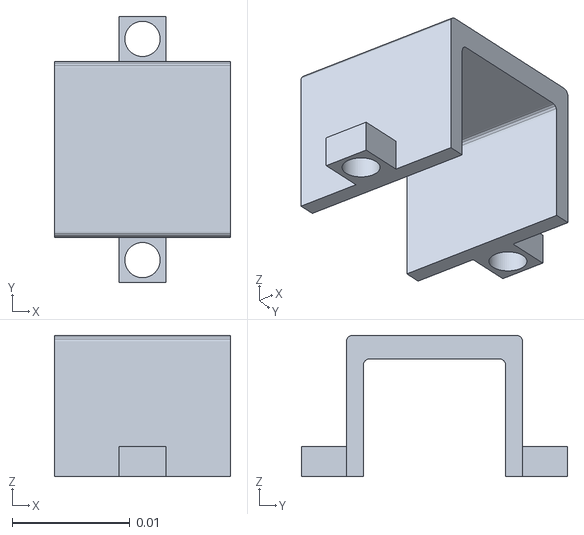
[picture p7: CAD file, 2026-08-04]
hardware/chassis/N20_motor_mount_v1.stl
0.015 x 0.0226 x 0.012

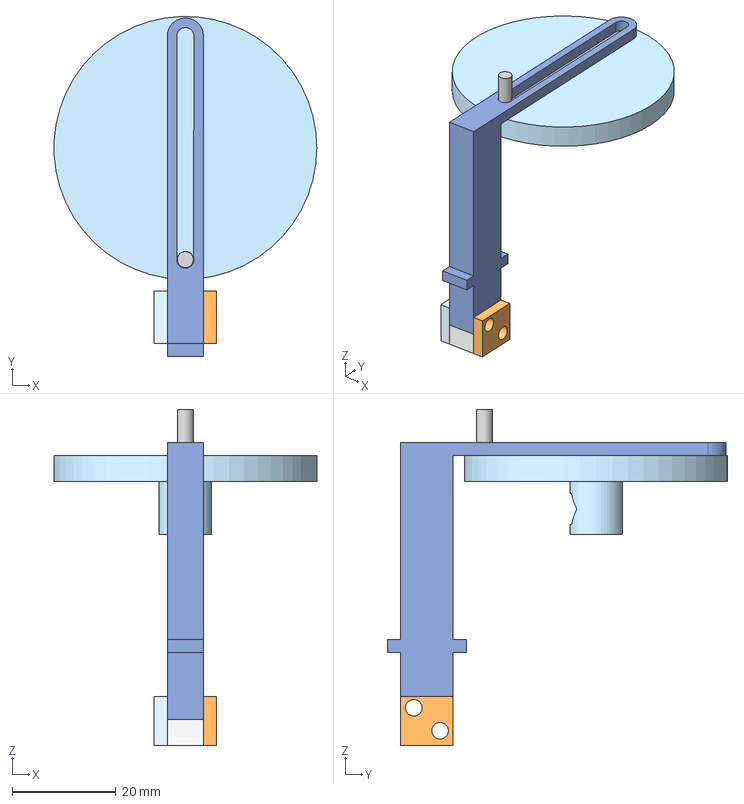
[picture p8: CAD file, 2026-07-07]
hardware/cleaning_mechanism/cleaning_mechanism_v3.step
50.8 x 65.7 x 64.9 mm

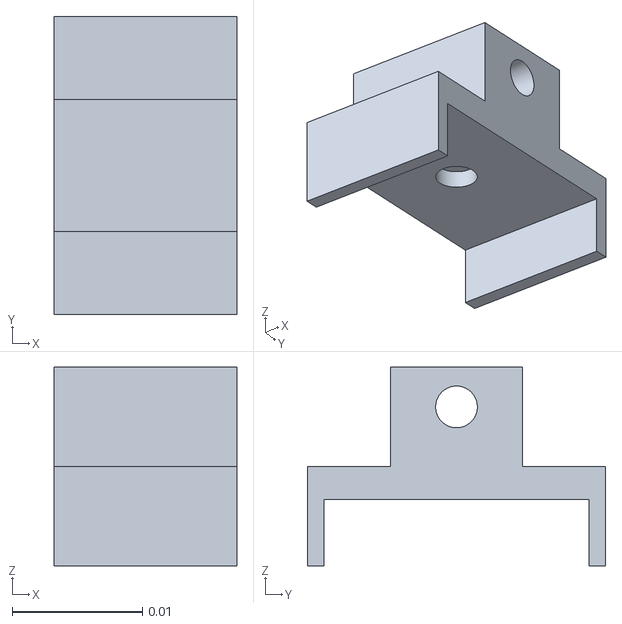
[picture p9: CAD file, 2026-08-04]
hardware/cleaning_mechanism/individual_parts/cleaning_mechanism_v4_connecting_magnet_piece.stl
0.014 x 0.0229 x 0.0152

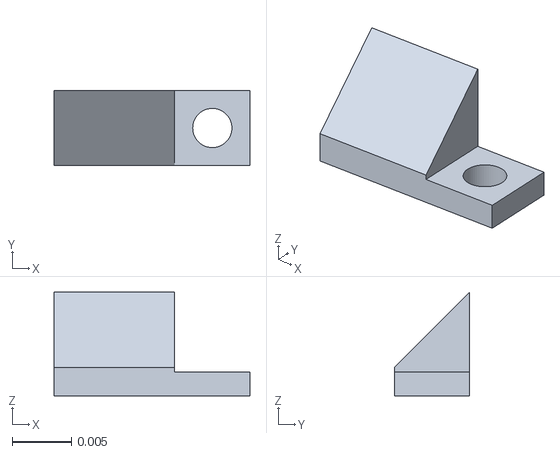
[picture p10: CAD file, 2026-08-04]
hardware/chassis/chassis_mount_voltage_regulator_driver_v1.stl
0.0165 x 0.00635 x 0.00873

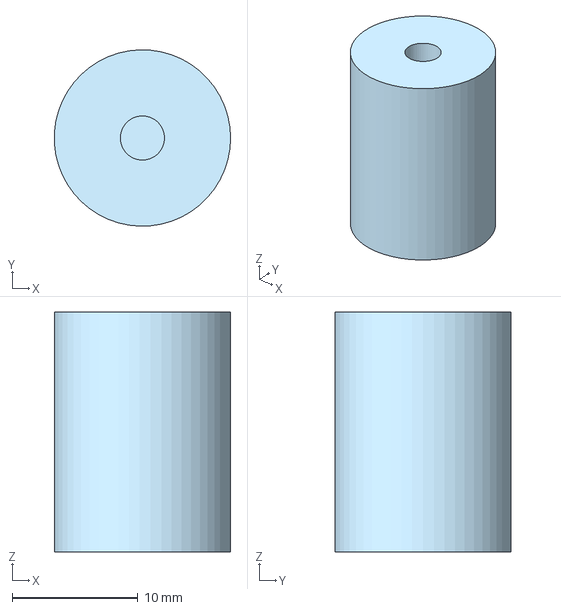
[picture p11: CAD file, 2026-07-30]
hardware/cleaning_mechanism/individual_parts/Plug for Cleaning Mechanism v1.step
14.0 x 14.0 x 19.1 mm

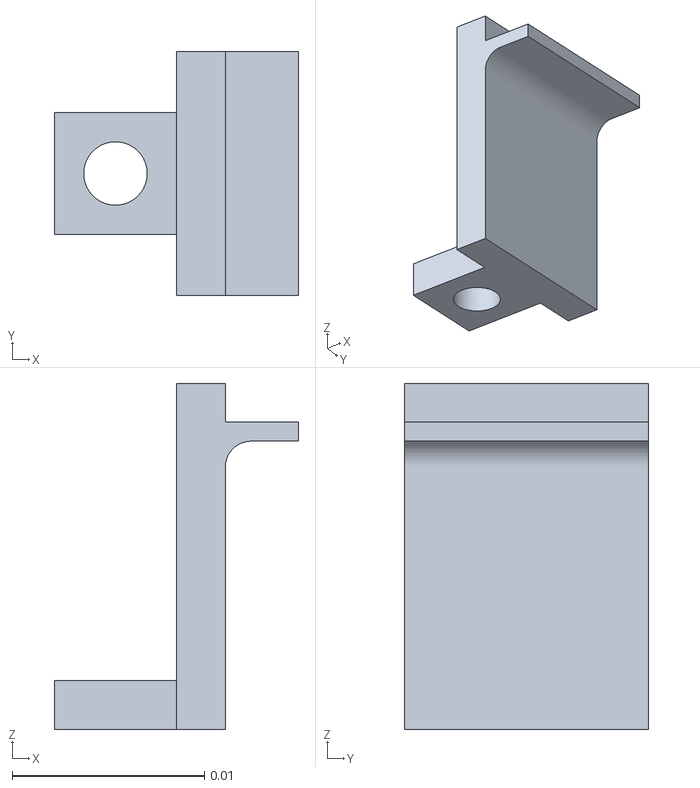
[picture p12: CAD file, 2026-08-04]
hardware/chassis/pcb_mount_2_v1.stl
0.0127 x 0.0127 x 0.018

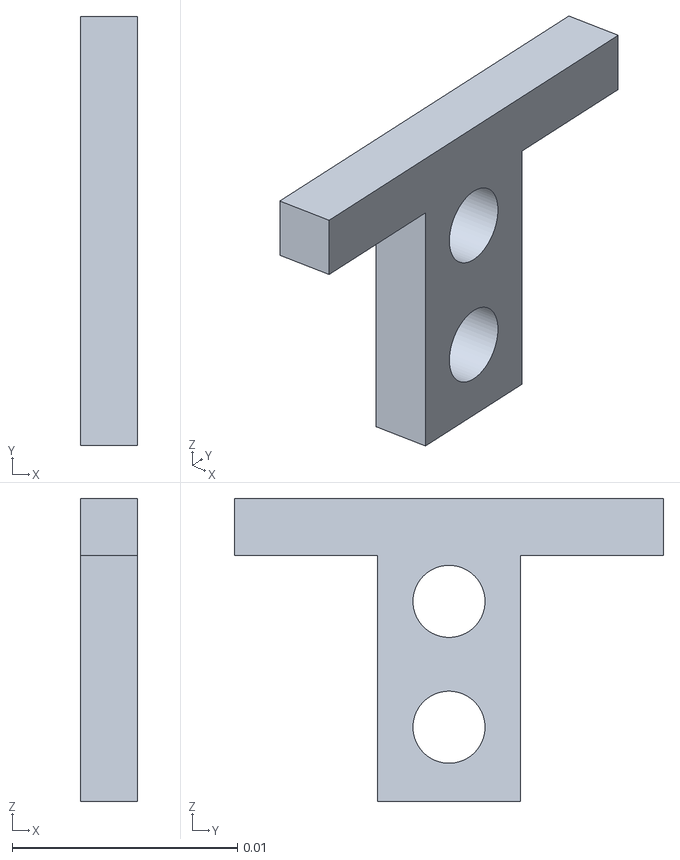
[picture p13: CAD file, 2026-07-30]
hardware/cleaning_mechanism/individual_parts/cleaning_mechanism_v4_bracket.stl
0.00254 x 0.0191 x 0.0135

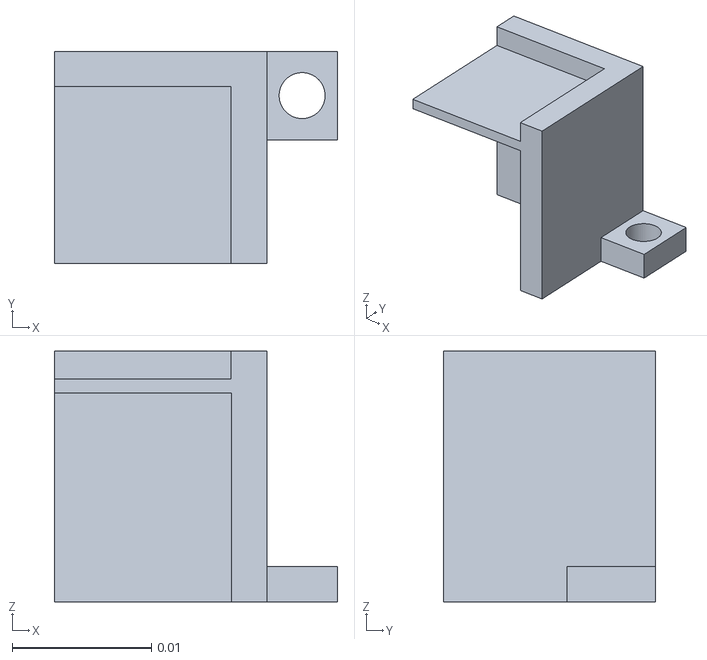
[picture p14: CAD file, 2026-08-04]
hardware/chassis/pcb_mount_1_v1.stl
0.0203 x 0.0152 x 0.018

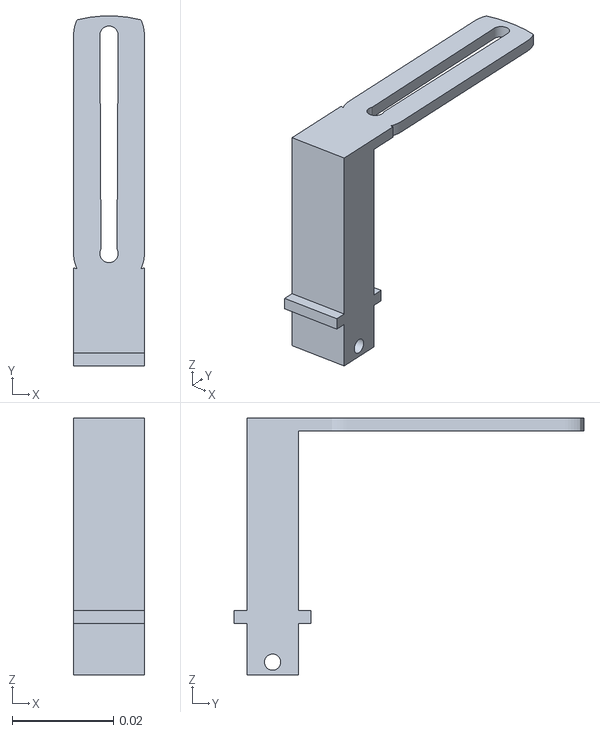
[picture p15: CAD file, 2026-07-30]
hardware/cleaning_mechanism/individual_parts/cleaning_mechanism_v4_sliding_arm.stl
0.014 x 0.0692 x 0.0508

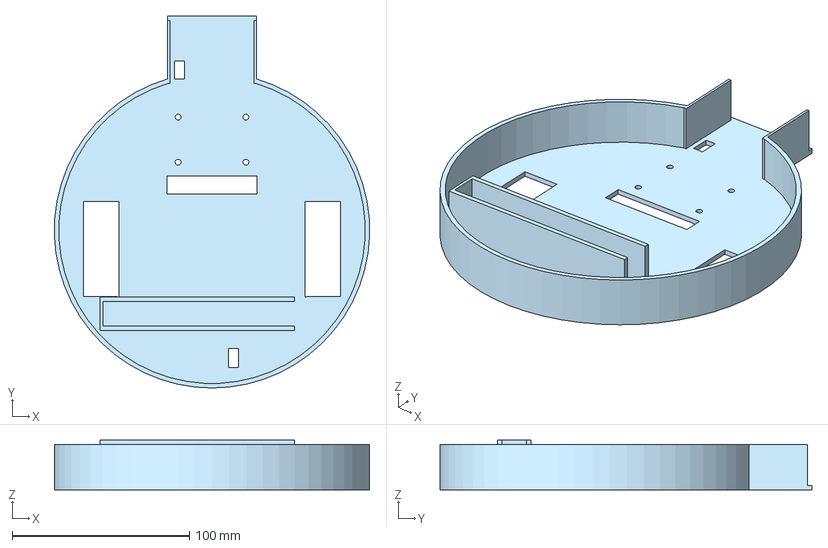
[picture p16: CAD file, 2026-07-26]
hardware/chassis/Chassis.v2.step
177.7 x 209.7 x 27.9 mm

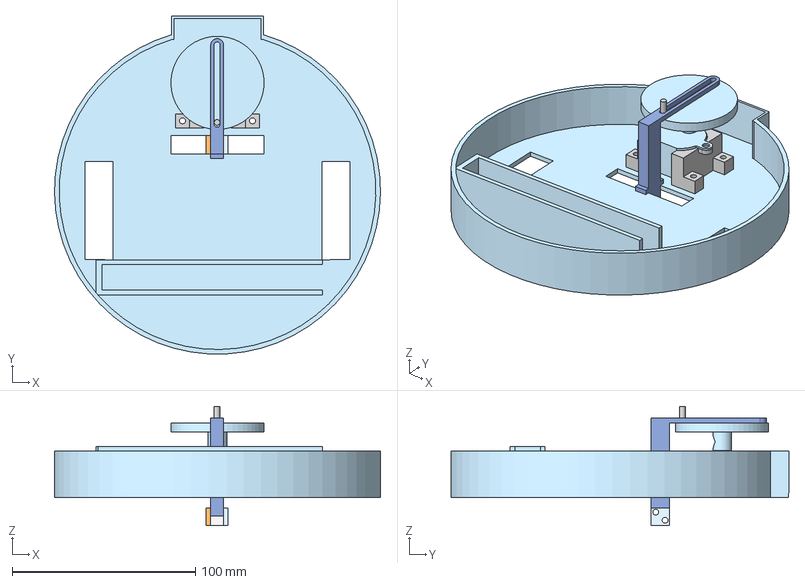
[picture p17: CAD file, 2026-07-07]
hardware/chassis/chassis_with_cleaning_mechanism_v1.step
177.8 x 184.2 x 64.9 mm
Motor Shaft
Chassis
Motor Body
Step Motor Mount

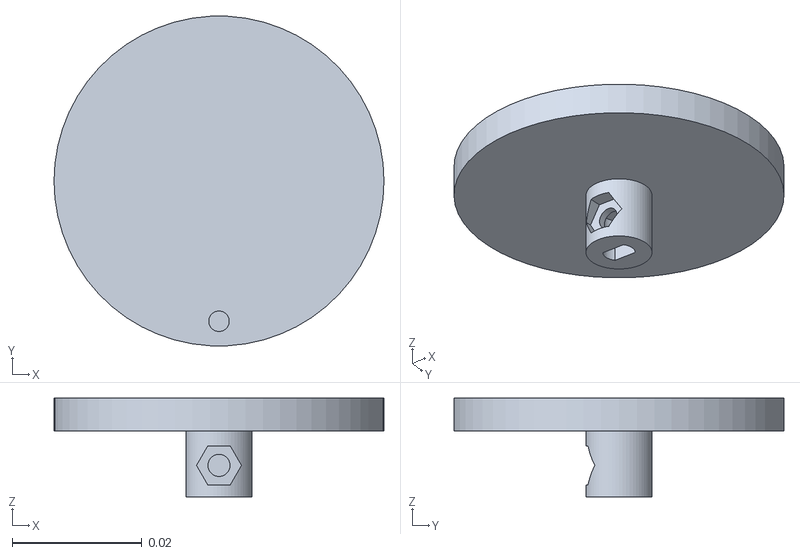
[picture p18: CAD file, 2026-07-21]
hardware/cleaning_mechanism/individual_parts/cleaning_mechanism_v3_crank_wheel.stl
0.0508 x 0.0507 x 0.0152

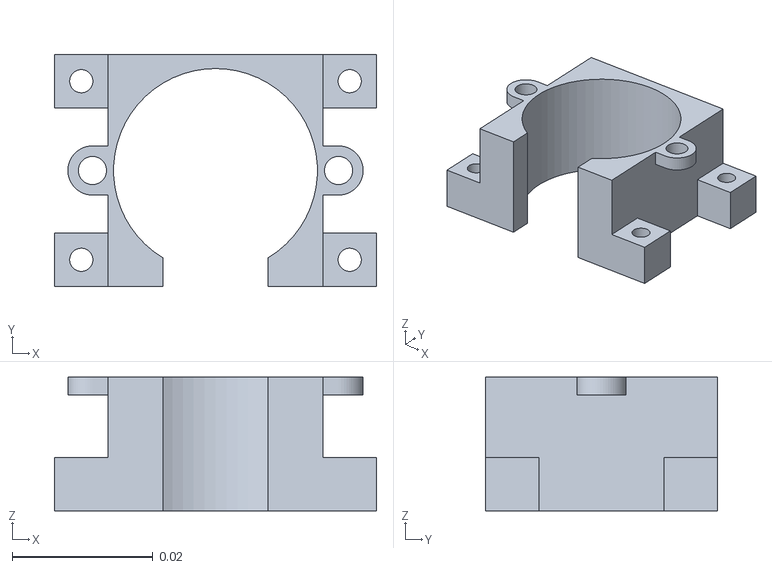
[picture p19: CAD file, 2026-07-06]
hardware/chassis/step_motor_mount_v1.stl
0.0458 x 0.033 x 0.0191

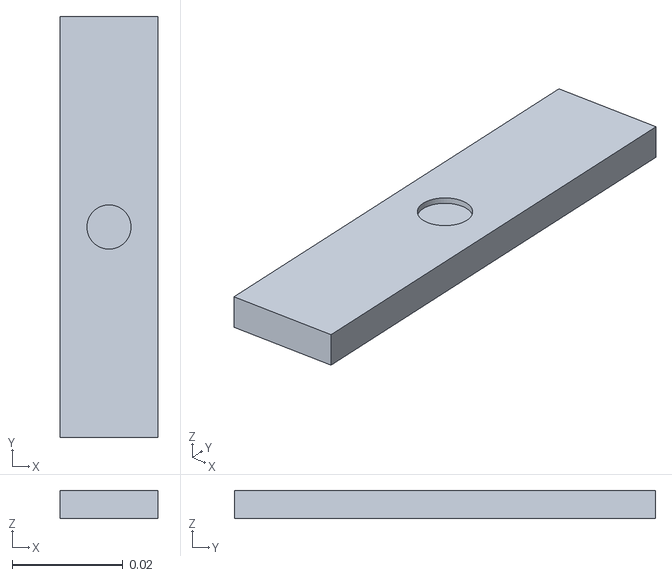
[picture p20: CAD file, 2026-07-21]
hardware/cleaning_mechanism/individual_parts/cleaning_mechanism_v3_cleaner_holding_piece.stl
0.0178 x 0.0762 x 0.00508

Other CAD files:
hardware/cleaning_mechanism/cleaning_mechanism_v2.stl
hardware/cleaning_mechanism/cleaning_mechanism_v1.step
hardware/cleaning_mechanism/individual_parts/cleaning_mechanism_v3_sliding_arm.stl
hardware/cleaning_mechanism/individual_parts/cleaning_mechanism_v3_bracket.stl
hardware/chassis/Chassis.v2.stl
hardware/chassis/chassis_v1.stl
hardware/chassis/chassis_with_cleaning_mechanism_v1.stl
hardware/cleaning_mechanism/cleaning_mechanism_v1.stl
hardware/cleaning_mechanism/cleaning_mechanism_v3.stl
hardware/cleaning_mechanism/individual_parts/Plug for Cleaning Mechanism v1.stl
hardware/cleaning_mechanism/individual_parts/cleaning_mechanism_v3_connecting_magnet_piece.stl

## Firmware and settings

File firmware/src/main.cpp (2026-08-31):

#include <Arduino.h>

#include "driver_motor_controls.hpp"
#include "sensor_controls.hpp"
#include "stepper_motor_controls.hpp"
#include "web_server.hpp"


const char* WIFI_SSID = "Pramod's iPhone";
const char* WIFI_PASSWORD = "sadmonkey26";

web_server server(WIFI_SSID, WIFI_PASSWORD);

drive_state last_state = drive_state::STOPPED;

void setup() {

Serial.begin(115200);
delay(1000);

    Serial.println("Starting WebController...");
   server.begin();  // connects WiFi, registers routes, starts server
    Serial.println("Ready. Try visiting the routes below in a browser.");
}

void loop() {
    server.update();  // watchdog check -- runs every pass, no exceptions

    drive_state current = server.get_current_command();

    // Only print when the state actually changes, so you get a clean log
    // instead of hundreds of identical lines per second
    if (current != last_state) {
        Serial.print("Command changed to: ");
        switch (current) {
            case drive_state::STOPPED:  Serial.println("STOPPED");  break;
            case drive_state::FORWARD:  Serial.println("FORWARD");  break;
            case drive_state::BACKWARD: Serial.println("BACKWARD"); break;
            case drive_state::TURNING_LEFT:     Serial.println("TURNING_LEFT");     break;
            case drive_state::TURNING_RIGHT:    Serial.println("TURNING_RIGHT");    break;
        }
        last_state = current;
    }

    // No delay() here on purpose -- this loop needs to spin fast so the
    // watchdog timeout (400ms) gets checked frequently and accurately.
}

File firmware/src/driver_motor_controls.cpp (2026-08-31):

#include "driver_motor_controls.hpp"



driver_motor_controls :: driver_motor_controls() : current_state(drive_state::STOPPED) {}

void driver_motor_controls :: begin() {

    pinMode(MOTOR_LEFT_INP_ONE, OUTPUT);
    pinMode(MOTOR_LEFT_INP_TWO, OUTPUT);
    pinMode(MOTOR_RIGHT_INP_ONE, OUTPUT);
    pinMode(MOTOR_RIGHT_INP_TWO, OUTPUT);
    
    ledcSetup(MOTOR_LEFT_SPEED_CHANNEL, 5000, 8);
    ledcAttachPin(MOTOR_LEFT_SPEED, MOTOR_LEFT_SPEED_CHANNEL);

    ledcSetup(MOTOR_RIGHT_SPEED_CHANNEL, 5000, 8);
    ledcAttachPin(MOTOR_RIGHT_SPEED, MOTOR_RIGHT_SPEED_CHANNEL);

    ledcWrite(MOTOR_LEFT_SPEED_CHANNEL, 255);
    ledcWrite(MOTOR_RIGHT_SPEED_CHANNEL, 255);
}

void driver_motor_controls :: forward() {

    current_state = drive_state :: FORWARD;
    //LEFT MOTOR CONTROLS
    digitalWrite(MOTOR_LEFT_INP_ONE, HIGH);
    digitalWrite(MOTOR_LEFT_INP_TWO, LOW);

    //RIGHT MOTOR CONTROLS
    digitalWrite(MOTOR_RIGHT_INP_ONE, HIGH);
    digitalWrite(MOTOR_RIGHT_INP_TWO, LOW);

}

void driver_motor_controls :: backward() {


    current_state = drive_state :: BACKWARD;

    //LEFT MOTOR CONTROLS
    digitalWrite(MOTOR_LEFT_INP_ONE, LOW);
    digitalWrite(MOTOR_LEFT_INP_TWO, HIGH);

    //RIGHT MOTOR CONTROLS 
    digitalWrite(MOTOR_RIGHT_INP_ONE, LOW);
    digitalWrite(MOTOR_RIGHT_INP_TWO, HIGH);

}

void driver_motor_controls :: turn_left() {

    current_state = drive_state :: TURNING_LEFT;

    //LEFT MOTOR
    digitalWrite(MOTOR_LEFT_INP_ONE, LOW);
    digitalWrite(MOTOR_LEFT_INP_TWO, LOW);

    //RIGHT MOTOR
    digitalWrite(MOTOR_RIGHT_INP_ONE, HIGH);
    digitalWrite(MOTOR_RIGHT_INP_TWO, LOW);

}

void driver_motor_controls :: turn_right() {

    current_state = drive_state :: TURNING_RIGHT;

    //LEFT MOTOR
    digitalWrite(MOTOR_LEFT_INP_ONE, HIGH);
    digitalWrite(MOTOR_LEFT_INP_TWO, LOW);

    //RIGHT MOTOR
    digitalWrite(MOTOR_RIGHT_INP_ONE, LOW);
    digitalWrite(MOTOR_RIGHT_INP_TWO, LOW);

}
void driver_motor_controls :: stop() {

    current_state = drive_state :: STOPPED;

    //LEFT MOTOR
    digitalWrite(MOTOR_LEFT_INP_ONE, LOW);
    digitalWrite(MOTOR_LEFT_INP_TWO, LOW);

    //RIGHT MOTOR 
    digitalWrite(MOTOR_RIGHT_INP_ONE, LOW);
    digitalWrite(MOTOR_RIGHT_INP_TWO, LOW);
}

drive_state driver_motor_controls :: get_state() {
    return current_state;
}

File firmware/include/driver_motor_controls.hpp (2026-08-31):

#ifndef DRIVER_MOTOR_CONTROLS_HPP
#define DRIVER_MOTOR_CONTROLS_HPP
#include "types.hpp"

#include <Arduino.h> 

//PIN DEFINITIONS FOR L293D
#define MOTOR_LEFT_INP_ONE  25
#define MOTOR_LEFT_INP_TWO  26
#define MOTOR_RIGHT_INP_ONE 27
#define MOTOR_RIGHT_INP_TWO 14
#define MOTOR_LEFT_SPEED    32
#define MOTOR_RIGHT_SPEED   33

#define MOTOR_LEFT_SPEED_CHANNEL 0
#define MOTOR_RIGHT_SPEED_CHANNEL 1


/**
 * driver_motor_controls represents the two wheel differential of the desktop cleaner robot. 
 * It uses two GA12-N20 motors and an L293D
 * 
 * Abstraction Function: 
 * AF(drive_state): current physical state of the robot's two drivetrain wheels in the 
 * present moment. 
 * 
 * Representation Invariants: 
 *  - current_state is always one of the defined drive state values
 *  - To avoid shorting L293D, both input pins of a single motor may never be 
 *    set to HIGH 
 **/


class driver_motor_controls {
    public:
       
        // constructor written for peace of mind
        driver_motor_controls();

        //defines all GPIO pins as OUTPUT, then sets the current driver state to stop
        void begin();

        //MOTOR OPERATIONS:
        void forward();
        void backward();
        void turn_left();
        void turn_right();
        void stop();
        void set_speed();
        drive_state get_state();
    private:
        drive_state current_state;
        
};
#endif

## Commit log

2026-05-05 Update README.md
    added information about the spray nozzle, included repo structure, and fixed some spelling errors
2026-05-05 Update design_decisions.md
    Decided on the chassis diameter
2026-05-11 Create materials purchased
    Added basic electronics kit
2026-05-11 Update and rename materials purchased to materials purchased.md
    fixed formatting issues
2026-05-12 Update design_decisions.md
    Added decision about drivetrain system for the robot
2026-05-14 Updated Repo Structure to include materials purchased
2026-05-14 Added design decision for layout
    Sketched preliminary chassis layout, and discovered I need to determine my scrubbing mechanism in order to fully decide on a layout
2026-05-14 Update current.md
    Added 5/14 log
2026-05-14 Added sketch of preliminary chassis layout
2026-05-21 Added today's log to current
2026-05-21 Updated Current Project Status and added hardware folder to Repo Structure
2026-05-26 Added STL and STEP files for cleaning mechanism prototype
    [cleaning_mechanism_v1.step, cleaning_mechanism_v1.stl]
2026-05-26 Logged today for current.md
2026-05-28 Changed From Step to Servo Motor
2026-05-29 Update components_list.md
    Added volate and current draw requirements. Added more components needed, such as DC motors, driver, stepper driver, and battery
2026-05-29 Update materials purchased.md
    Bought three new things today.
2026-05-29 Update design_decisions.md
    Decided on the quantity and placement of the IR sensors.
2026-05-29 Update current.md
    Added 5/29 message
2026-06-02 updated design decisions for wheel decision and added relevant sketch
2026-06-02 added v2 of the cleaning mechanism and updated current
    [cleaning_mechanism_v2.stl]
2026-06-17 updated components list and materials purchased
2026-06-25 updated design decisions and current
    [cleaning_mechanism_v1.step, cleaning_mechanism_v1.stl, cleaning_mechanism_v2.stl]
2026-06-25 updated design decisions and current and added chassis v1 model
    [chassis_v1.stl]
2026-07-06 Added step motor mount to hardware file and a related design decision
    [step_motor_mount_v1.stl]
2026-07-07 added files of cleaning mechanism by itself and with chassis
    [chassis_with_cleaning_mechanism_v1.step, chassis_with_cleaning_mechanism_v1.stl, cleaning_mechanism_v3.step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]
2026-07-18 updated compoenents list and materials bought list
2026-07-21 added individual parts for 3D printing
    [cleaning_mechanism_v3_bracket.stl, cleaning_mechanism_v3_cleaner_holding_piece.stl, cleaning_mechanism_v3_connecting_piece.stl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]
2026-07-21 Accidentally uploaded wrong file to git
    [cleaning_mechanism_v3_sliding_arm.stl]
2026-07-21 updated materials purchased log
2026-07-21 Added initial circuit sketch and corresponding design decision
2026-07-24 Logged design decision about changing from power supply module
2026-07-26 Added chassis files for 3D prinitng
    [Chassis.v2.step, Chassis.v2.stl]
2026-07-30 Added CAD files and corresponding design decision
    [Plug for Cleaning Mechanism v1.step, Plug for Cleaning Mechanism v1.stl, cleaning_mechanism_v4_connecting_piece.stl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]
2026-08-04 Added various mounts for 3D printing today
    [N20_motor_mount_v1.stl, chassis_mount_voltage_regulator_driver_v1.stl, pcb_mount_1_v1.stl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]
2026-08-04 updated design decisions and file names
    [cleaning_mechanism_v3_connecting_magnet_piece.stl, cleaning_mechanism_v4_bracket.stl, cleaning_mechanism_v4_connecting_magnet_piece.stl]
2026-08-10 Added photos of old PCB, current chassis, and cleaning mechanism to media folder
2026-08-14 made Many changes to the firmware folder, and solifided code for sensors, stepper motor, and driver motors
2026-08-31 added more code for the web server and crashed out with claude
    [driver_motor_controls.cpp, driver_motor_controls.hpp, main.cpp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]
2026-09-04 Changed the README to be a little bit more general and updated the currently doing section
